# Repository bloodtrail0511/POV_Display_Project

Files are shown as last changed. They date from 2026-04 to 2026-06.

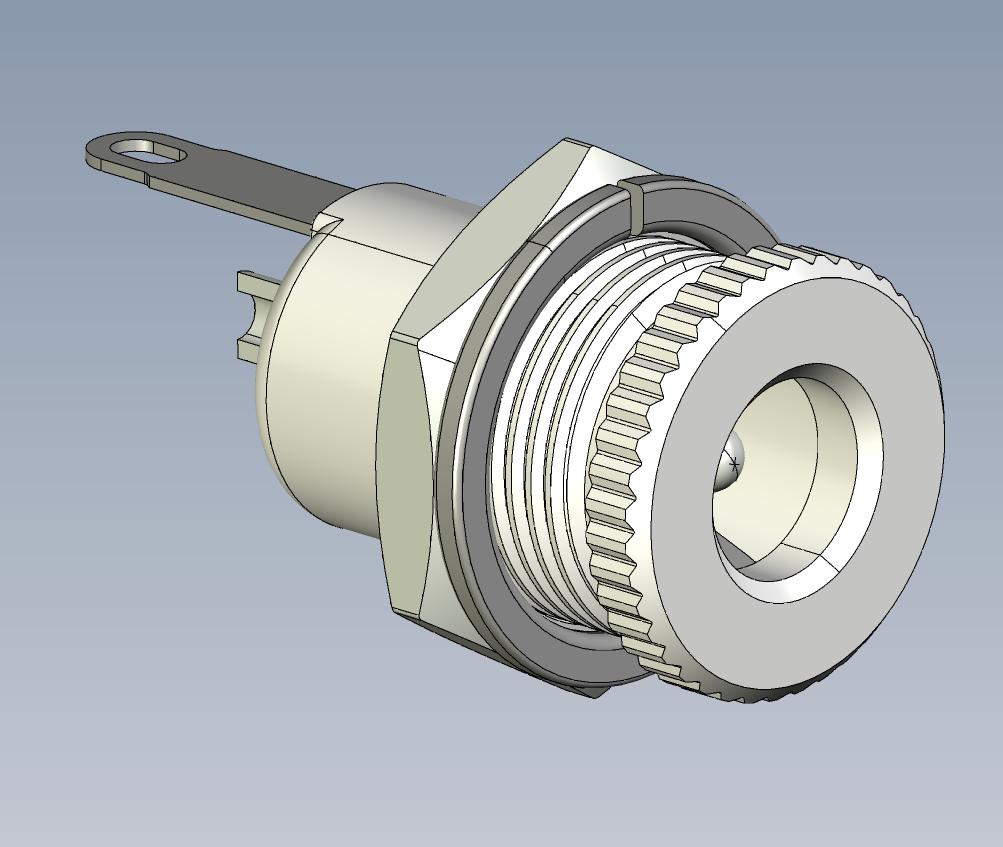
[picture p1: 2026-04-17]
src_by_members/314511041/solidworks_model/connector-5-5x2-1-dc00990-b-1.snapshot.1/Connector_5,5-2,1_DC00990-B_01.png

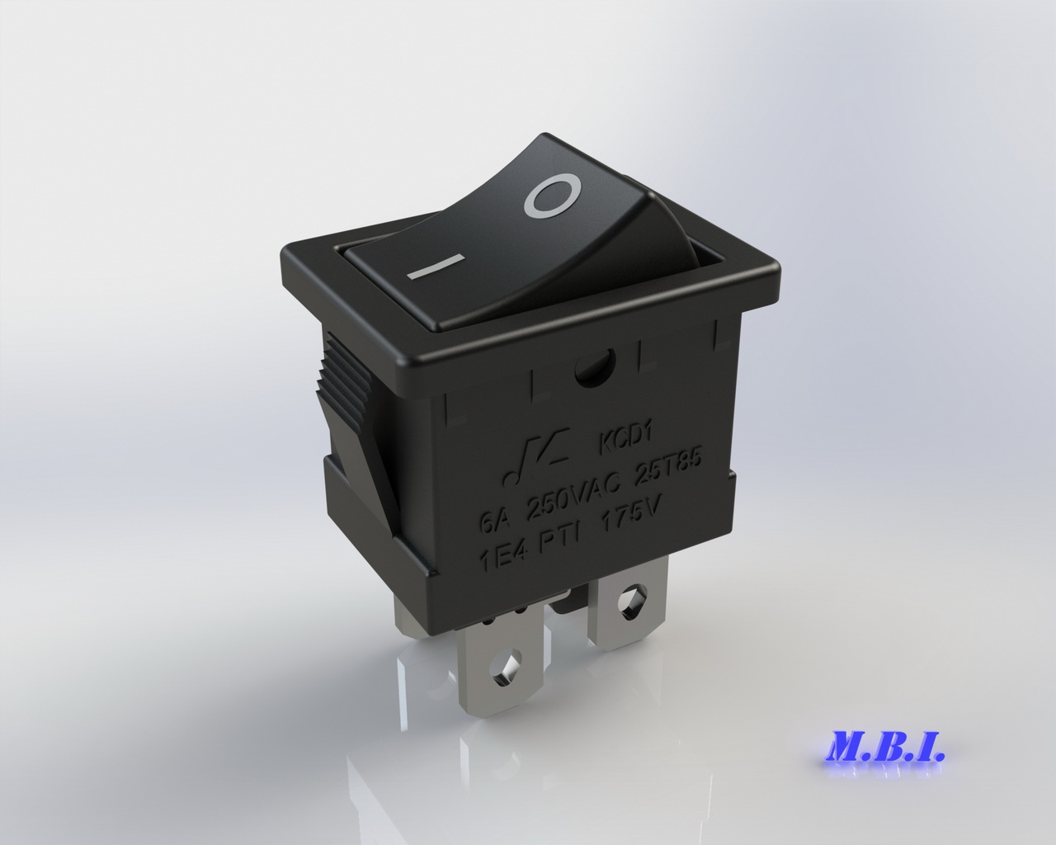
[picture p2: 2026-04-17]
src_by_members/314511041/solidworks_model/rocker-switch-kcd1-104-1.snapshot.1/Renderings/Rocker Switch KCD1-104 IMG_02.JPG

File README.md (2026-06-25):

# 視覺暫留 (POV) 互動遊戲顯示器

本專案是一個基於 Raspberry Pi 與 Linux 作業系統開發的 360 度環狀立體顯示螢幕。利用視覺暫留 (Persistence of Vision, POV) 原理結合高速旋轉的 APA102 LED 燈條，並透過自定義的 Linux Character Device Driver 達到極低延遲的硬體中斷與畫面同步，實現高流暢度的互動遊戲與多媒體展示。

## ✨ 核心技術與系統特色

* **Device Tree Overlay (DTS) 硬體綁定**：撰寫 `.dts` 檔案關閉預設的 `spidev`，將 SPI0 硬體節點直接交由自訂的驅動程式接管，突破 User Space Scheduler 的時間延遲限制。
* **即時硬體同步 (Real-time Synchronization)**：實作 Hall Sensor 核心驅動，精準記錄觸發時間 (`ktime`)，並透過低通濾波演算法計算轉速，解決高速旋轉時的畫面抖動問題。
* **核心級雙重緩衝 (Double Buffering)**：在 Kernel Space 實作 Double Buffer，利用 `Spinlock` 保護共享資源。唯有在 Hall Sensor 觸發 0 度回呼 (Callback) 時才進行畫面交換，完美解決畫面撕裂 (Tearing) 現象。
* **非同步 SPI 傳輸 (Async SPI)**：使用 `hrtimer` 以極高頻率觸發 SPI 傳輸，並利用 `atomic_t` 實作 Busy Flag，防止傳輸重疊。
* **TCP Client-Server 架構**：分離主機端 (Server) 與手把端 (Client)。使用 `SIGIO` 非同步訊號讀取硬體按鍵，透過 Socket 實現多玩家即時連線。
* **虛擬模擬器 (Virtual Device)**：內建基於 OpenCV 開發的虛擬模擬器，可在無實體硬體的情況下，直接於 PC 端進行 UI 渲染、狀態機 (FSM) 轉換與遊戲邏輯的開發。

## 📂 專案目錄結構
```
POV-Display-Project/
├── README.md               # 專案介紹與使用說明
├── Makefile                # 專案頂層控制 Makefile (統籌整體自動化編譯)
├── docs/                   # 存放專題說明文件與簡報
│   └── EOS-Final.pdf
├── dts/                    # 裝置樹重疊設定檔 (Device Tree Overlay)
│   └── pov_apa102.dts
├── drivers/                # Linux 核心驅動程式 (Kernel Space)
│   ├── Makefile            # 核心模組專用 Kbuild Makefile
│   ├── magnet_driver.c     # 霍爾感測器驅動
│   ├── my_btn_driver_v2.c  # 手把按鍵驅動 (Debounce 機制)
│   └── pov_display_driver_v3.c # APA102 SPI 顯示驅動
├── server/                 # 顯示器主機端主程式 (User Space)
│   ├── main_test.cpp
│   ├── main_test_sim.cpp   # PC 端虛擬模擬器
│   ├── pov_display.cpp
│   └── pov_display.hpp
├── client/                 # 遙控器手把端程式 (User Space)
│   └── controller_client.cpp
├── scripts/                # 開機自動化與網路連線腳本
│   ├── pov_auto.service
│   ├── start_client.sh
│   └── start_server.sh
└── assets/                 # 執行時期需要的圖片與影片資源
    ├── icon/
    └── video/
```
* `Makefile` : 編譯所需檔案
* `dts/`：包含 `pov_apa102.dts`，用於重新定義 Raspberry Pi 的 SPI 腳位對應。
* `drivers/`：包含三個 Linux Kernel Modules (`.ko`)。
  * `magnet_driver.c`：霍爾感測器 ISR 與轉速濾波。
  * `my_btn_driver_v2.c`：包含 `delayed_work` 軟體防彈跳 (Debounce) 的按鍵驅動。
  * `pov_display_driver_v3.c`：APA102 LED 燈條 SPI 渲染與時序控制驅動。
* `server/`：主機端應用程式 (C++)，負責 OpenCV 影像處理、狀態機邏輯與 Socket 監聽。
* `client/`：手把端應用程式 (C++)，負責讀取本機驅動訊號並透過 TCP 傳送。
* `scripts/`：NetworkManager 自動連線腳本與 systemd service 設定，實現設備開機自動連線與執行。

## 🚀 編編譯與執行方式

### 1. 修改目錄
將 Makefile 裡面的 `KDIR` 修改為實際用於樹莓派或交叉編譯的 Linux 核心原始碼樹（Kernel Source Tree）目錄。例如：
```makefile
KDIR = /home/ouo/master_degree/class/eos/linux-origin
```

### 2. 編編譯檔案
在開發主機的專案根目錄下執行以下指令，編譯驅動程式、手把端程式與裝置樹重疊檔：
```bash
make all
```

### 3. 檔案上傳
分別將編譯完成的驅動、執行檔與相關腳本透過 `scp` 上傳至對應的 Server、Client 樹莓派（例如工作目錄 `/home/rtes/`）：

**Server (主機端樹莓派) 需上傳：**
* 核心驅動模組：`magnet_driver.ko`、`pov_display_driver_v3.ko`、`my_btn_driver_v2.ko`
* 裝置樹重疊檔：`pov_apa102.dtbo`
* 主程式原始碼：`main_test_serverjoin.cpp`、`pov_display.cpp`、`pov_display.hpp`
* 自動化腳本與服務：`start_server.sh`、`pov_auto.service`
* 多媒體資源資料夾：`assets/`（包含 `icon/` 與 `video/`，務必與主程式放在同一層目錄）

**Client (手把端樹莓派)：**
* 核心驅動模組：`my_btn_driver_v2.ko`
* 交叉編譯執行檔：`controller_client`
* 自動化腳本與服務：`start_client.sh`、`pov_auto.service`

### 4. 在樹莓派(Server)執行main_test.cpp的編譯
登入 Server 樹莓派後，切換至擺放原始碼的目錄，執行以下命令編譯結合 OpenCV 與多執行緒的 POV 主程式：
```bash
g++ -o main_test_serverjoin main_test_serverjoin.cpp pov_display.cpp $(pkg-config --cflags --libs opencv4) -lpthread
```

### 5. 複製DTBO並執行指令
在 **Server 樹莓派** 上，將裝置樹重疊檔複製到系統韌體目錄下：
```bash
sudo cp pov_apa102.dtbo /boot/firmware/overlays/
```
編輯開機組態設定檔以啟用自訂的 overlay：
```bash
sudo nano /boot/firmware/config.txt
```
在檔案的最末端加上以下設定：
```text
dtoverlay=pov_apa102
```
*修改完成後存檔退出，並重啟樹莓派 (`sudo reboot`) 以載入 `/dev/pov_display` 與 `/dev/mag_sensor` 設備節點。*

### 6. 啟用服務設定開機自啟動
請先確認兩台樹莓派上的 `pov_auto.service` 服務檔內，其 `WorkingDirectory` 與 `ExecStart` 腳本（`start_server.sh` / `start_client.sh`）的**絕對路徑**皆正確無誤。接著在兩台樹莓派上分別執行：
```bash
sudo cp pov_auto.service /etc/systemd/system/pov_auto.service
sudo systemctl daemon-reload
sudo systemctl enable pov_auto.service
sudo systemctl start pov_auto.service
```
若需要查看自動啟動與雙機 Wi-Fi 通訊的即時 Debug 日誌，可執行：
```bash
sudo journalctl -u pov_auto.service -f
```

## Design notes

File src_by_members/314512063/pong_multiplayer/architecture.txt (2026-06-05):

Pong Game
|
|-- app_pong_multi.cpp
|   |
|   |-- main game loop
|   |-- OpenCV 畫面
|   |-- Pong 物理
|   |-- P1 / P2 本機擋板
|   |-- P3 / P4 網路擋板
|   |-- POV simulator
|   |-- include "net_server.hpp"
|
|-- net_server.hpp
|   |
|   |-- NetPlayerInput 結構宣告
|   |-- net_players[] 宣告
|   |-- 最多 2 位外部玩家
|   |-- start_network_server()
|   |-- stop_network_server()
|
|-- net_server.cpp
|   |
|   |-- TCP socket server
|   |-- bind() / listen()
|   |-- accept thread
|   |-- client thread
|   |-- P3 / P4 玩家分配
|   |-- atomic input state
|   |-- mutex player allocation
|
|-- pong_client.cpp
|   |
|   |-- 玩家端程式
|   |-- 連線到 server IP
|   |-- 上下鍵控制
|   |-- 傳送 UP / DOWN / QUIT

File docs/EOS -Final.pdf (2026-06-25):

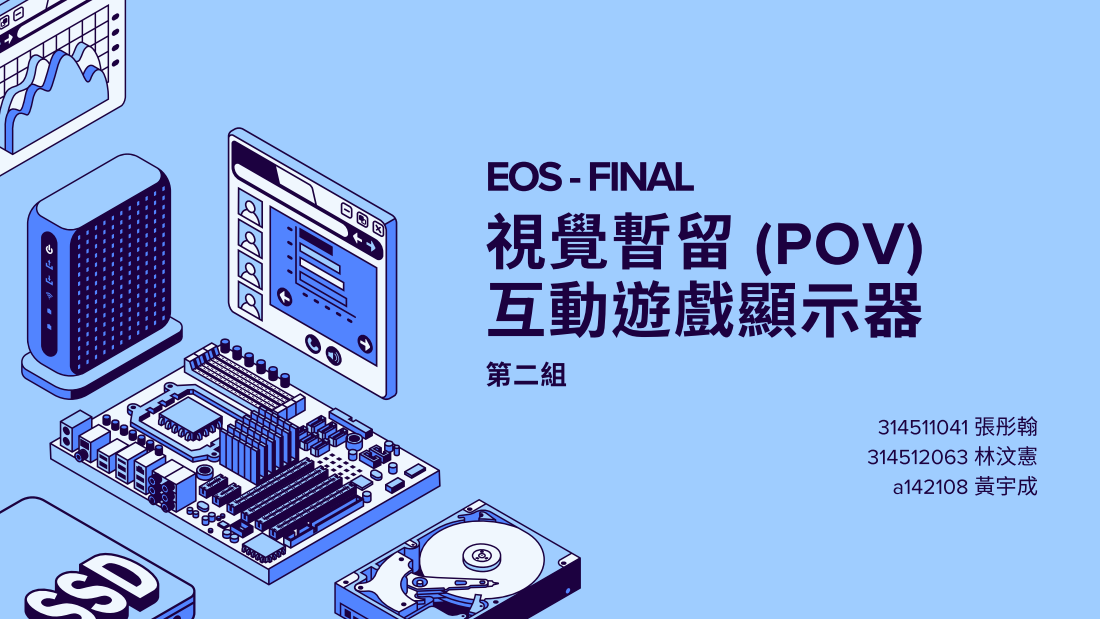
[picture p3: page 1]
EOS-FINAL 視覺暫留 (POV) 互動遊戲顯示器; 第二組; 314511041 張彤翰; 314512063 林汶憲; a142108 黃宇成

# 專題說明-視覺暫留(POV)互動遊戲顯示器

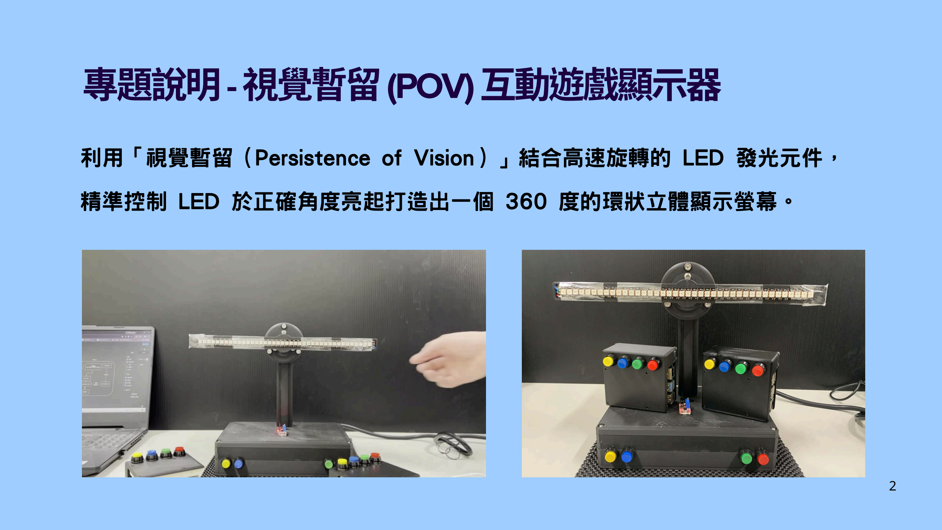
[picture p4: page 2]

利用「視覺暫留（Persistence of Vision）」結合高速旋轉的 LED 發光元件，

精準控制 LED 於正確角度亮起打造出一個 360 度的環狀立體顯示螢幕。

2

## 系統連線架構(TCPclient-server)

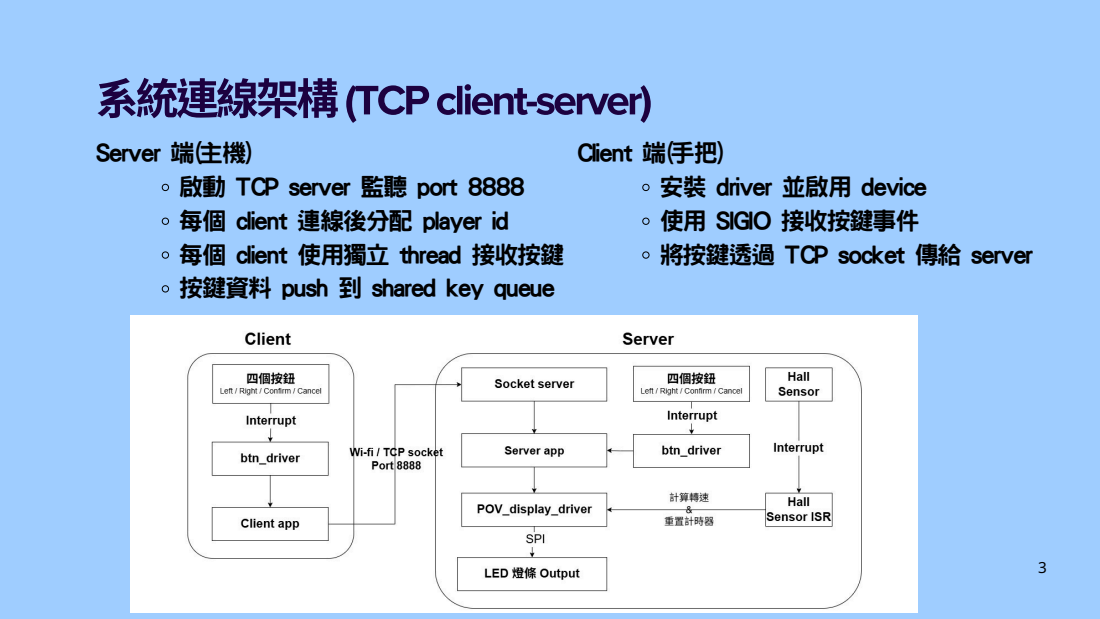
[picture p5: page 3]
Server 端(主機); Client 端(手把)

啟動 TCP server 監聽 port 8888
每個 client 連線後分配 player id
每個 client 使用獨立 thread 接收按鍵
按鍵資料 push 到 shared key queue

安裝 driver 並啟用 device
使用 SIGIO 接收按鍵事件
將按鍵透過 TCP socket 傳給 server

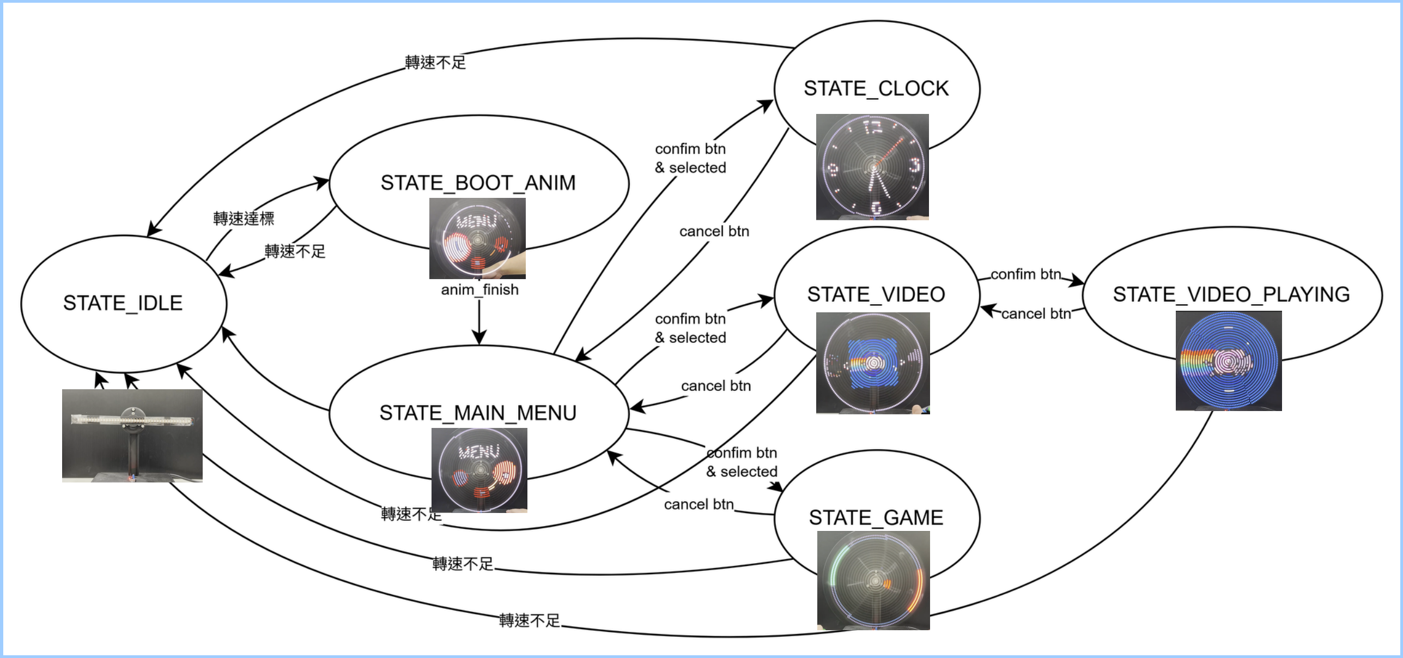
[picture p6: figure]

4

## ServerFSM 架構

主程式使用狀態機 FSM，管理整個系統流程

5

# KernelSpace

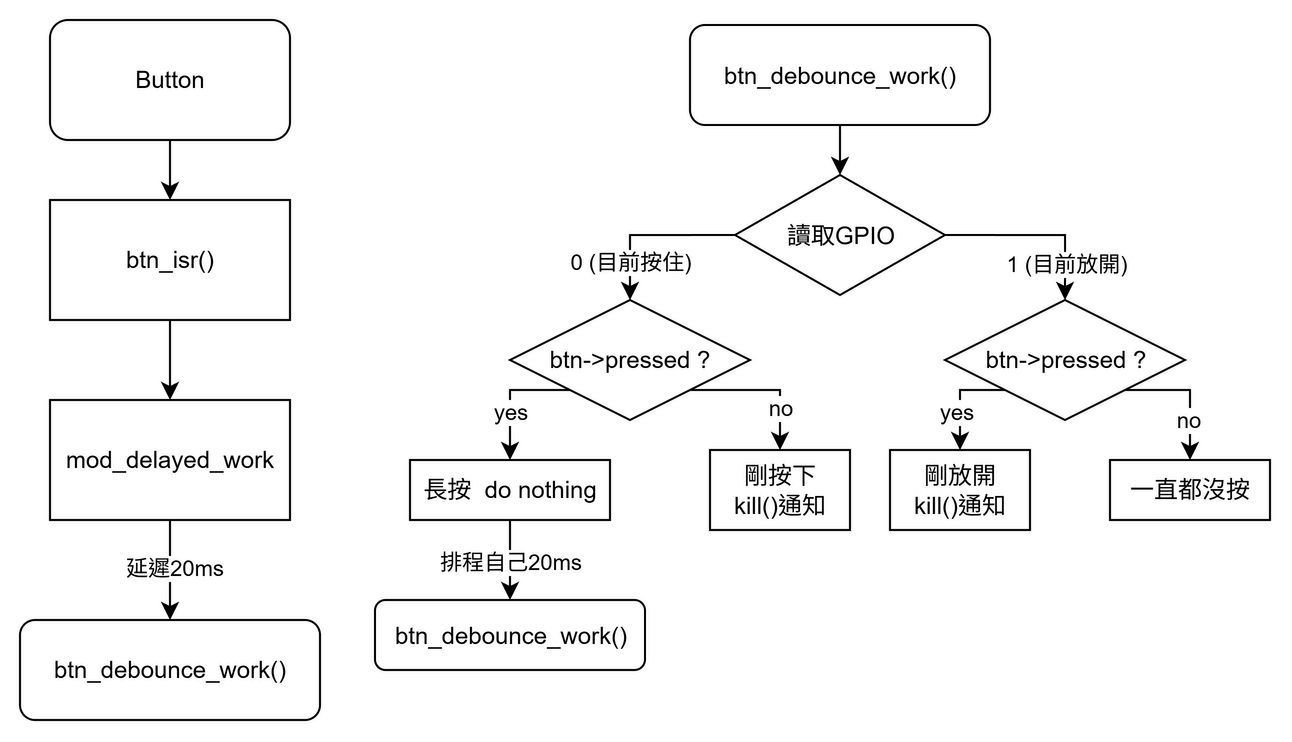
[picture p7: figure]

6

四顆按鍵：left、right、confirm、cancel

ISR 偵測按下與放開，signal通知userspace讀

取狀態

Worker task 實作 debounce 與與狀態判斷

即使放開時 rising interrupt 沒有觸發，

delayed work 也會在下一次檢查時發現已經

release。

## ButtonDriver :遙控器按鈕

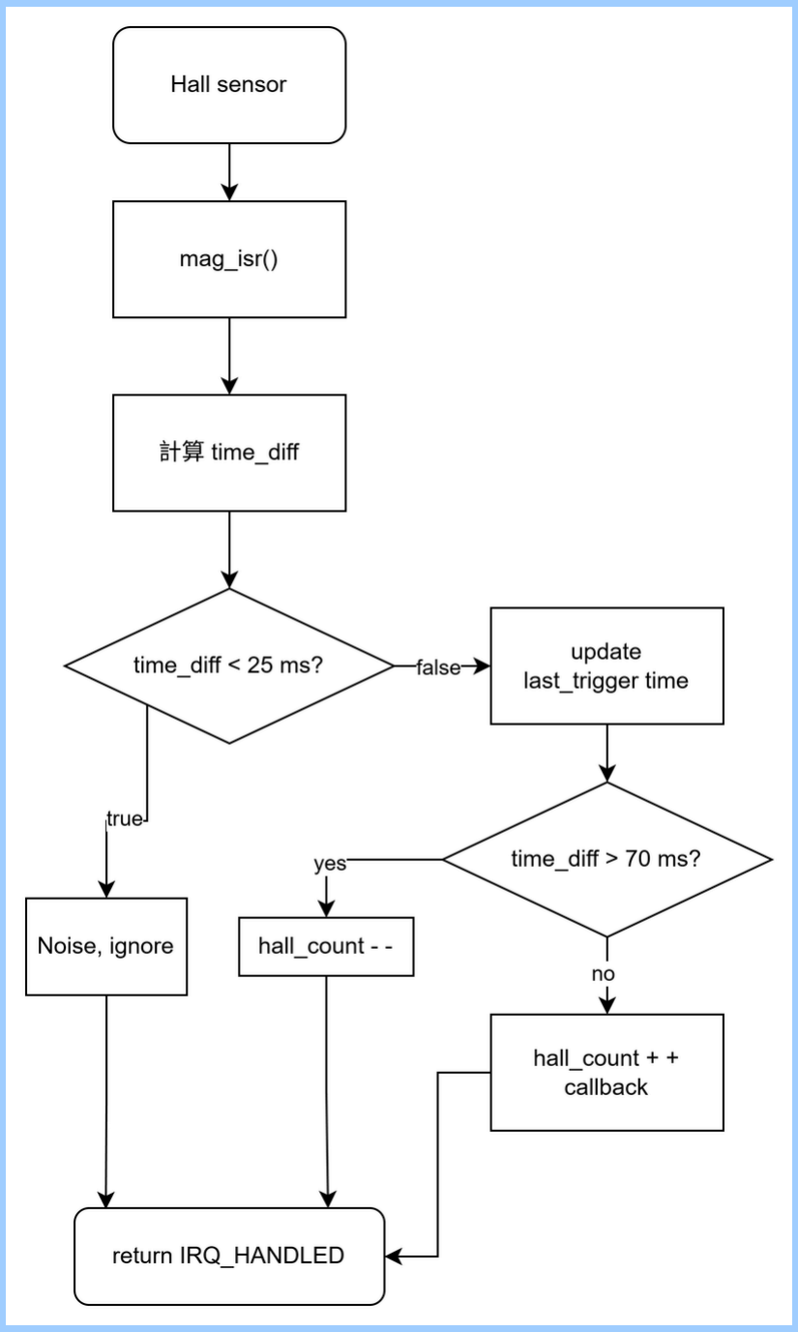
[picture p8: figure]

7

## MagnetDriver : POV系統的角度同步來源

接收 Hall Sensor 的 interrupt 與轉速判斷

記錄每次 Hall 觸發時間，計算並過濾不合理週期，保留穩定轉速

給 userspace 判斷是否正在旋轉，避免誤判

將觸發時間 callback 給 POV driver 進行同步

## POVDisplayDriver : POV顯示

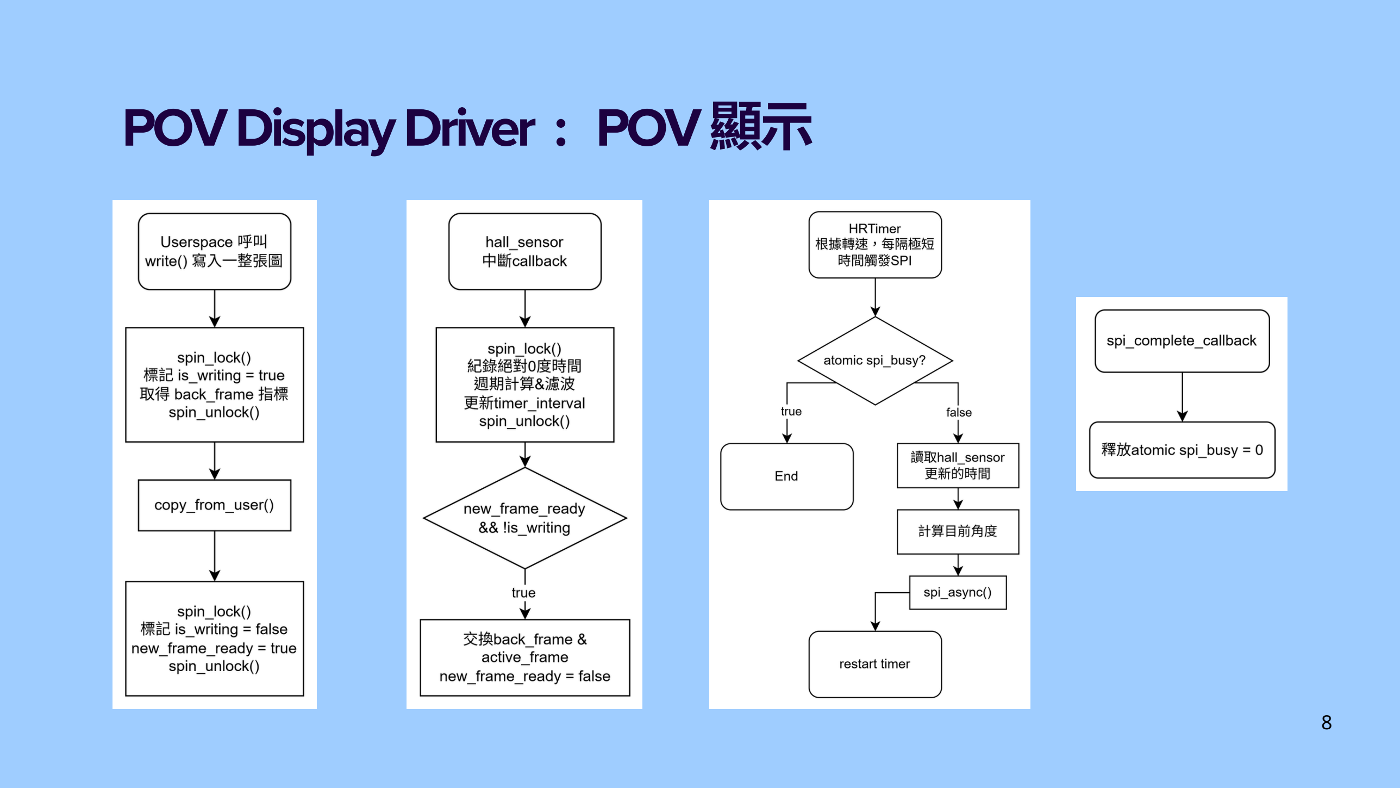
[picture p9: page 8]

8

## POVDisplayDriver-Synchronization

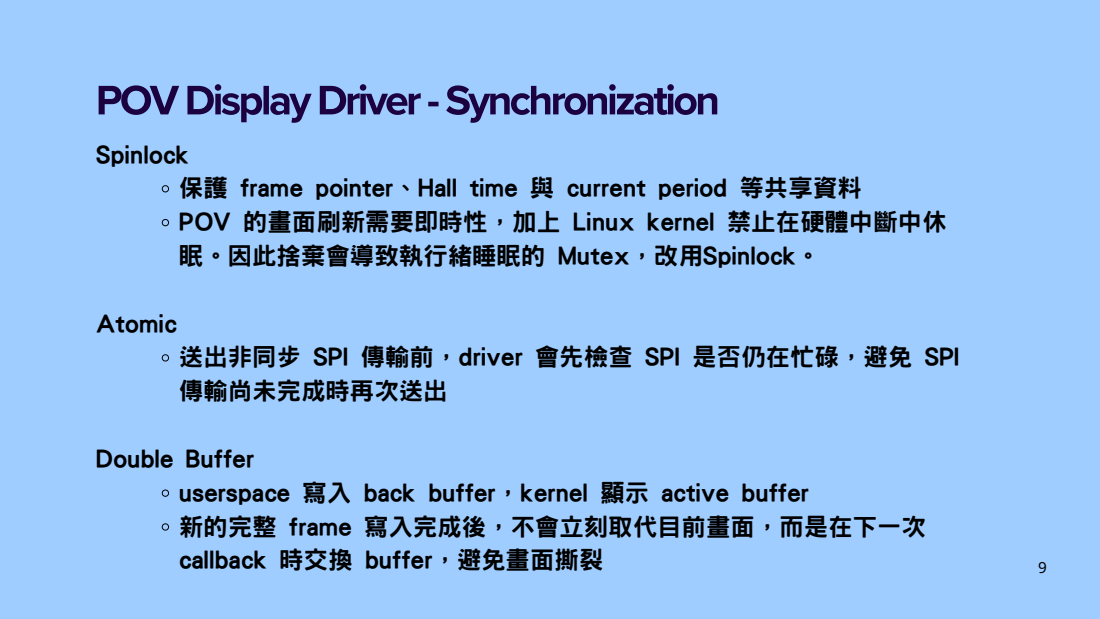
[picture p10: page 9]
Spinlock; Atomic; Double Buffer

保護 frame pointer、Hall time 與 current period 等共享資料
POV 的畫面刷新需要即時性，加上 Linux kernel 禁止在硬體中斷中休
眠。因此捨棄會導致執行緒睡眠的 Mutex，改用Spinlock。

送出非同步 SPI 傳輸前，driver 會先檢查 SPI 是否仍在忙碌，避免 SPI
傳輸尚未完成時再次送出

userspace 寫入 back buffer，kernel 顯示 active buffer
新的完整 frame 寫入完成後，不會立刻取代目前畫面，而是在下一次
callback 時交換 buffer，避免畫面撕裂

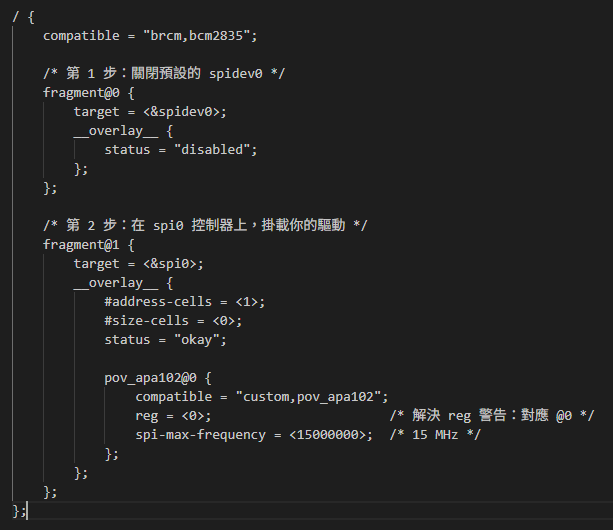
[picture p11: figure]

10

## POVDisplayDriver-DeviceTreeOverlay

為何不直接用 spidev？
RPi 提供的 spidev 只能於 Userspace 使用， 容易受Scheduler影響導致時間延遲
解法：
撰寫自訂的 SPI Client Driver 與 .dts（編譯 成 .dtbo）。讓 Linux 啟動並掃描 Device Tree 時，直接將SPI硬體節點綁定到 POV
driver 中並與其他功能整合，建立完整的即時
顯示流程

11

# UserspaceSpace

# 使用的OS機制

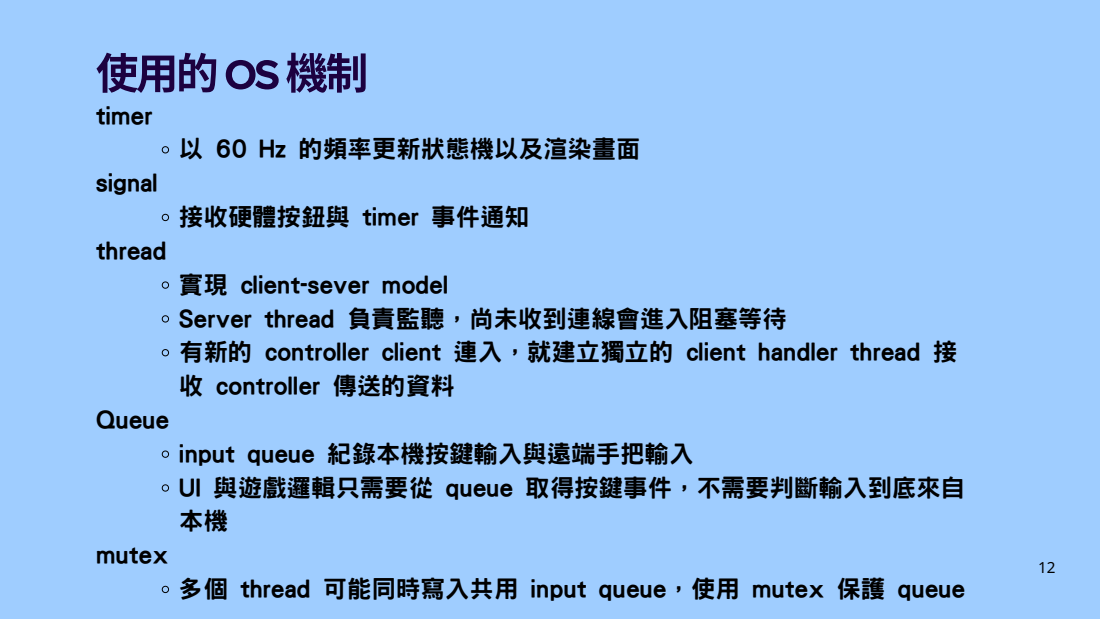
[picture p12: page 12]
timer; 以 60 Hz 的頻率更新狀態機以及渲染畫面; signal; thread; Queue; mutex

接收硬體按鈕與 timer 事件通知

實現 client-sever model
Server thread 負責監聽，尚未收到連線會進入阻塞等待
有新的 controller client 連入，就建立獨立的 client handler thread 接
收 controller 傳送的資料

input queue 紀錄本機按鍵輸入與遠端手把輸入
UI 與遊戲邏輯只需要從 queue 取得按鍵事件，不需要判斷輸入到底來自

多個 thread 可能同時寫入共用 input queue，使用 mutex 保護 queue

## POVDisplayClass

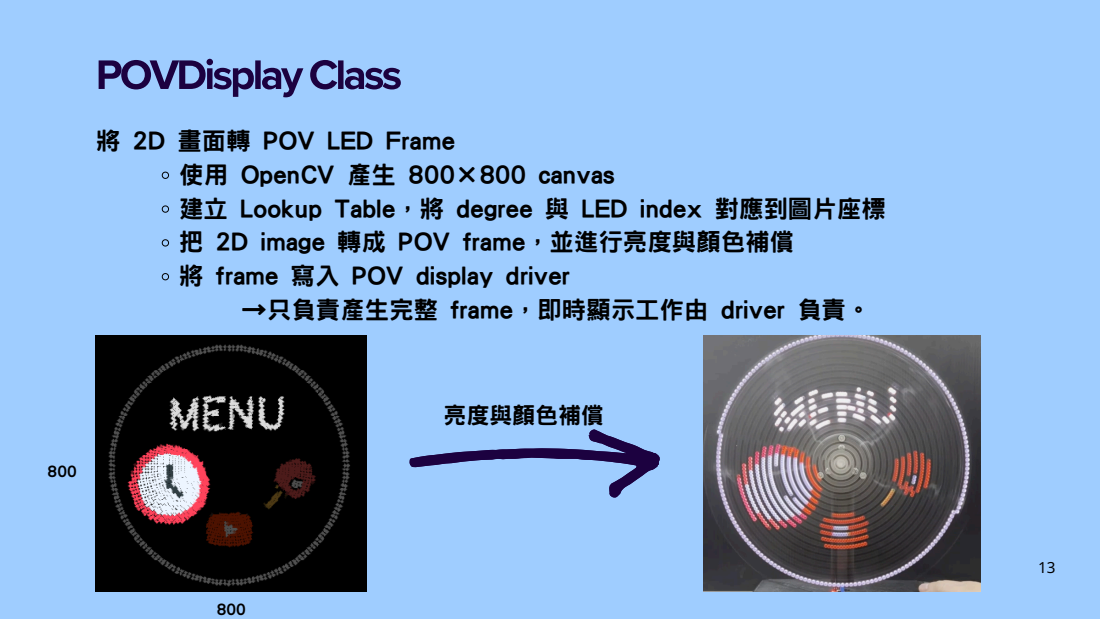
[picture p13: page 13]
亮度與顏色補償

將 2D 畫面轉 POV LED Frame

使用 OpenCV 產生 800×800 canvas
建立 Lookup Table，將 degree 與 LED index 對應到圖片座標
把 2D image 轉成 POV frame，並進行亮度與顏色補償
將 frame 寫入 POV display driver
→只負責產生完整 frame，即時顯示工作由 driver 負責。

## VirtualDevice模擬器

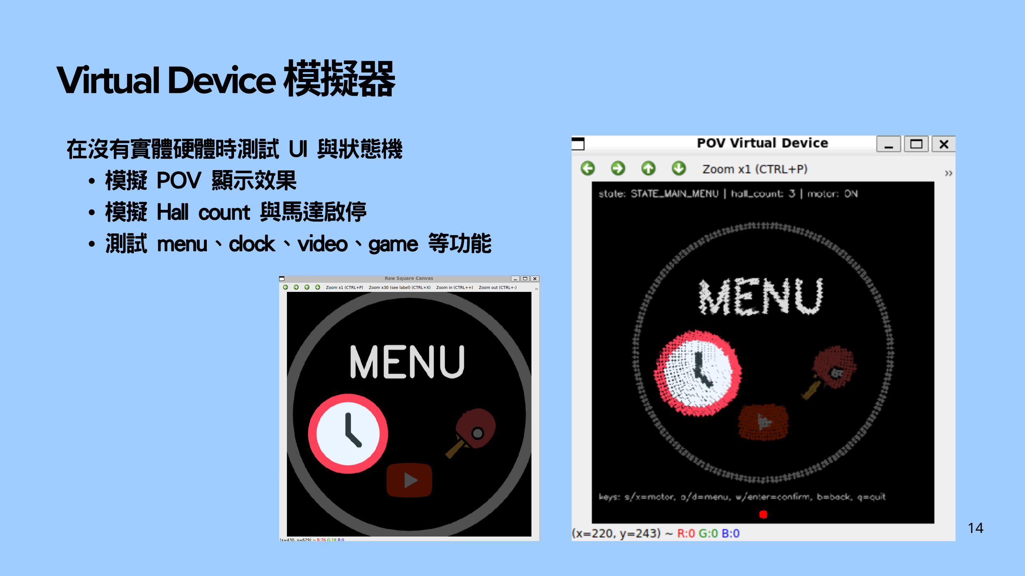
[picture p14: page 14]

14

在沒有實體硬體時測試 UI 與狀態機
模擬 POV 顯示效果
模擬 Hall count 與馬達啟停
測試 menu、clock、video、game 等功能

15

# Demo

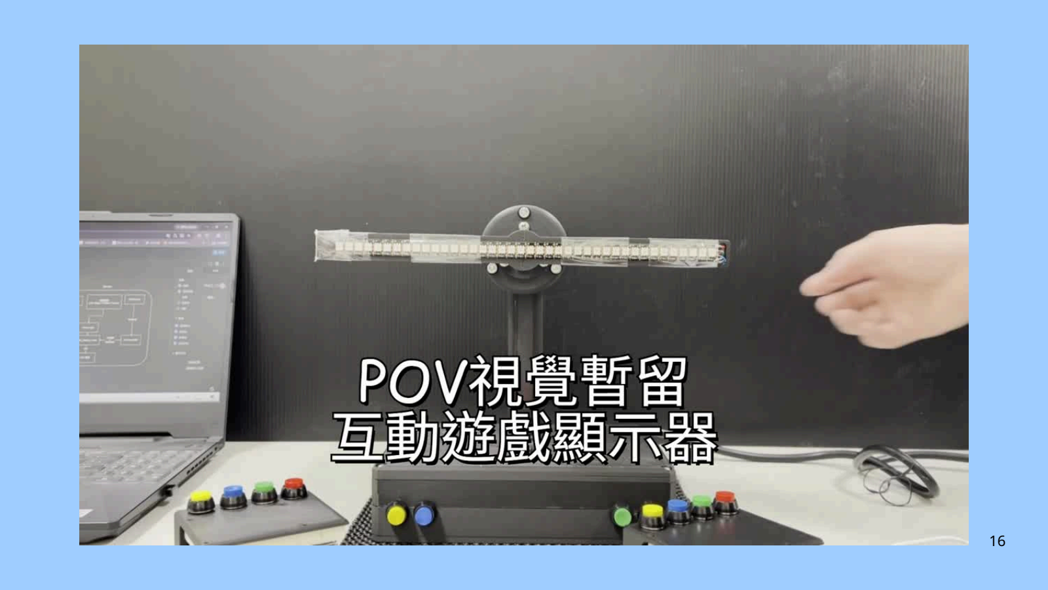
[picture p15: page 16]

16

# 遇到的問題與解決方法

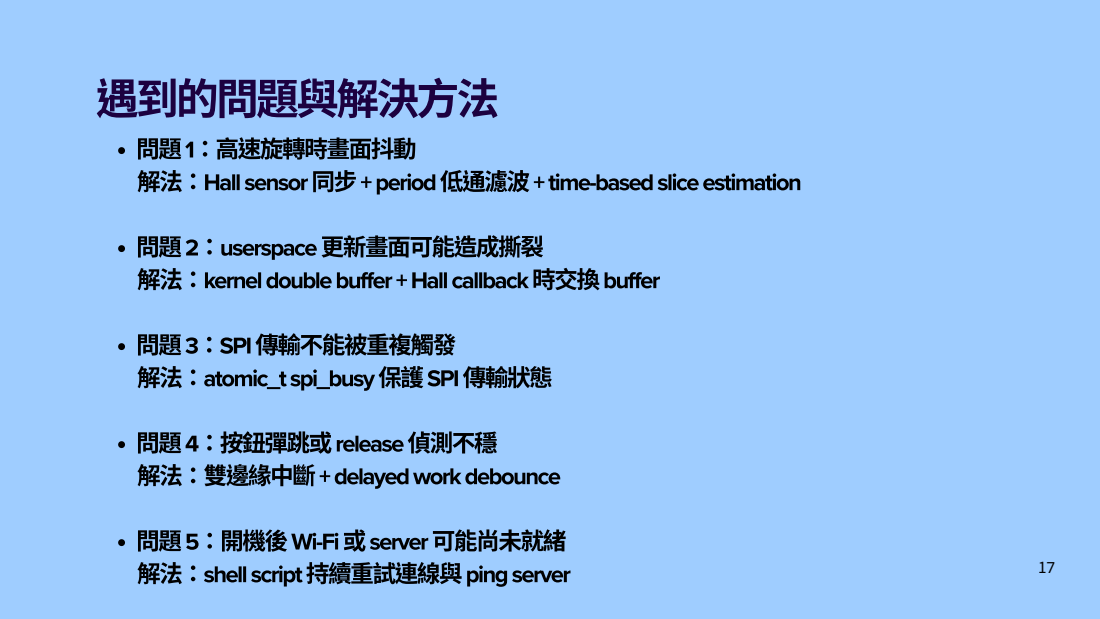
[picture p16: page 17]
問題3：SPI傳輸不能被重複觸發; 解法：atomic_t spi_busy保護SPI傳輸狀態

問題1：高速旋轉時畫面抖動
解法：Hall sensor同步+period低通濾波+ time-basedsliceestimation

問題2：userspace更新畫面可能造成撕裂
解法：kerneldoublebuffer +Hall callback時交換buffer

問題4：按鈕彈跳或release偵測不穩
解法：雙邊緣中斷+delayedworkdebounce

問題5：開機後Wi-Fi或server可能尚未就緒
解法：shell script持續重試連線與pingserver

# 本專題使用到的EOS概念

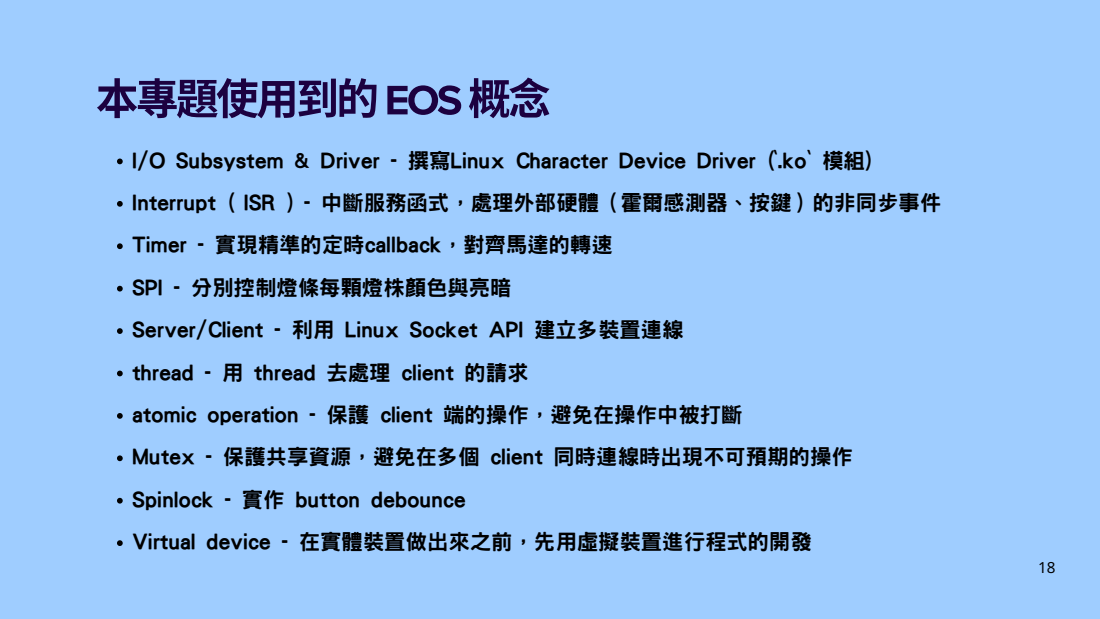
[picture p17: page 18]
SPI - 分別控制燈條每顆燈株顏色與亮暗

I/O Subsystem & Driver - 撰寫Linux Character Device Driver (`.ko

Interrupt ( ISR ) - 中斷服務函式，處理外部硬體（霍爾感測器、按鍵）的非同步事件

Timer - 實現精準的定時callback，對齊馬達的轉速

Server/Client - 利用 Linux Socket API 建立多裝置連線

thread - 用 thread 去處理 client 的請求

atomic operation - 保護 client 端的操作，避免在操作中被打斷

Mutex - 保護共享資源，避免在多個 client 同時連線時出現不可預期的操作

Spinlock - 實作 button debounce

Virtual device - 在實體裝置做出來之前，先用虛擬裝置進行程式的開發

19

Q&A

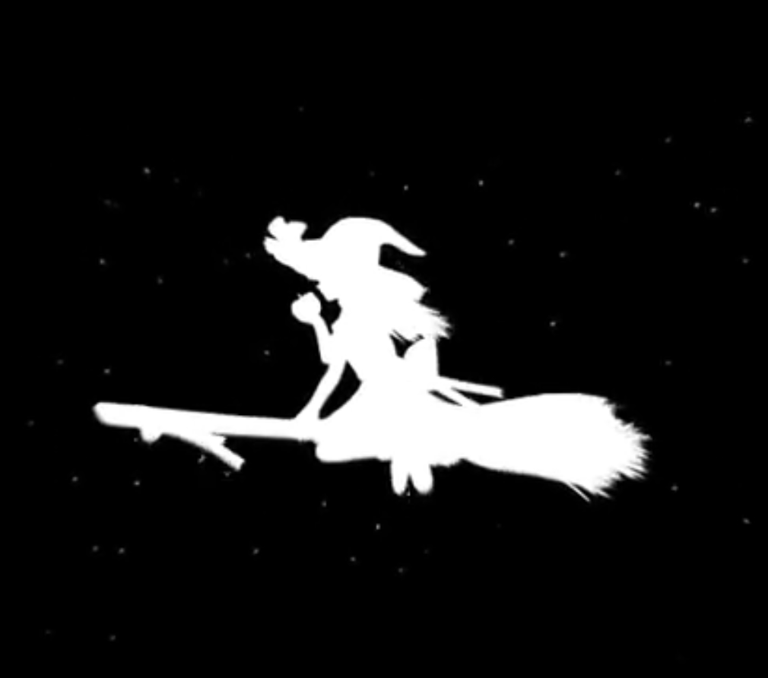
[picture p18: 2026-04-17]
src_by_members/314511041/bad_apple.png

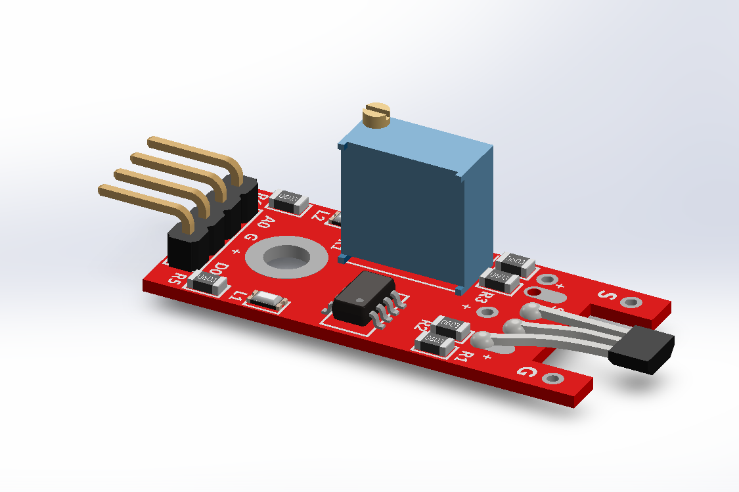
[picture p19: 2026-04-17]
src_by_members/314511041/solidworks_model/hall-effect-sensor-2.snapshot.2/Hall Effect Sensor.png

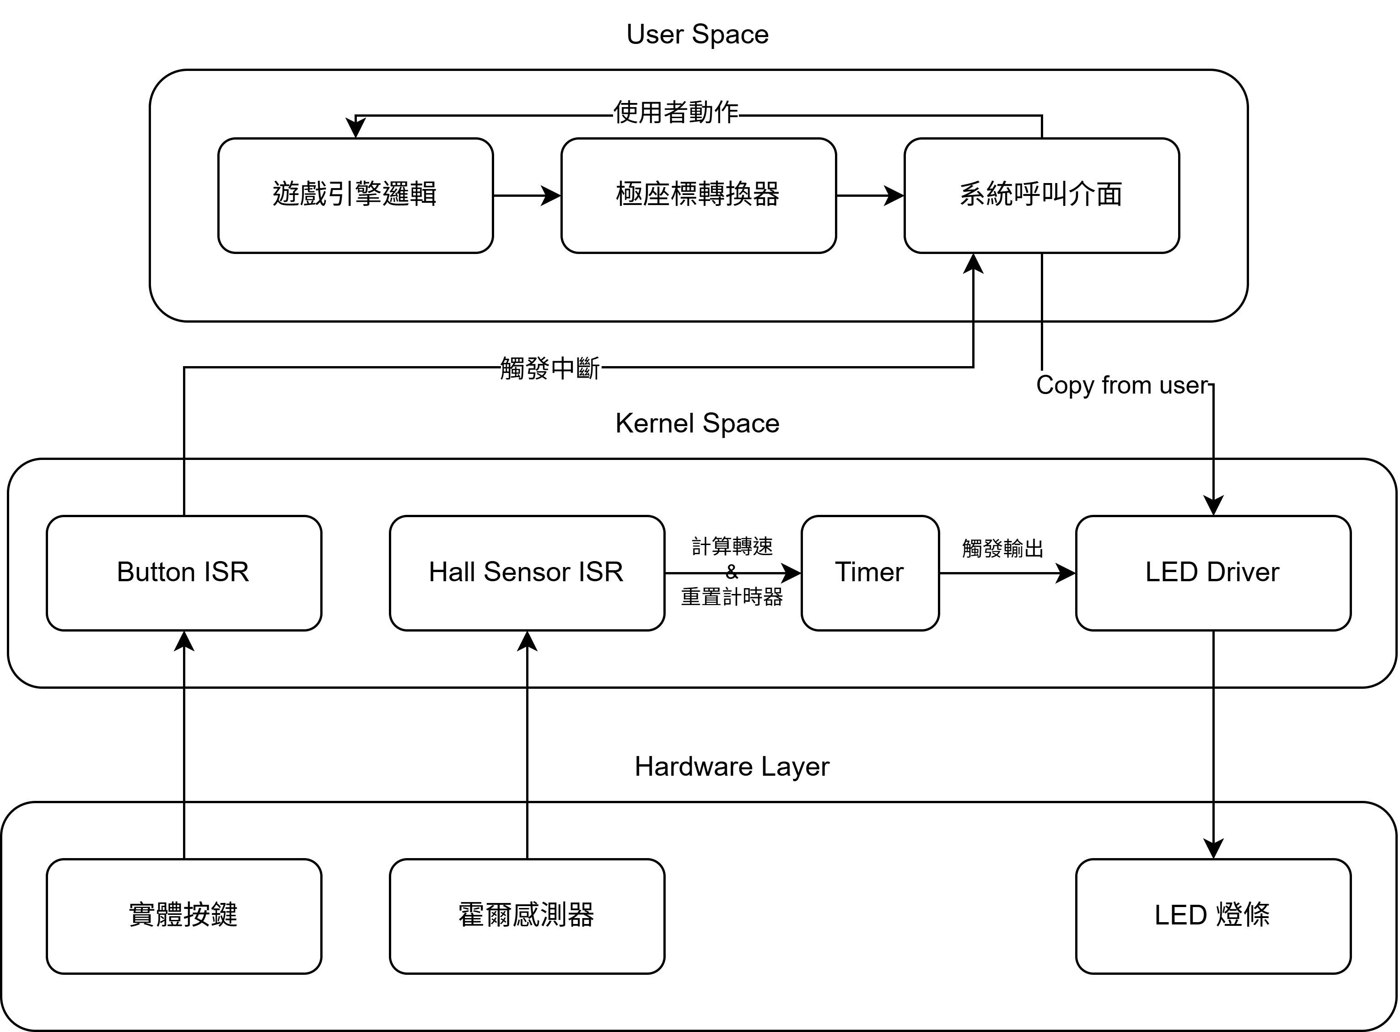
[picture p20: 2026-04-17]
src_by_members/314511041/from_vm/系統架構圖.png

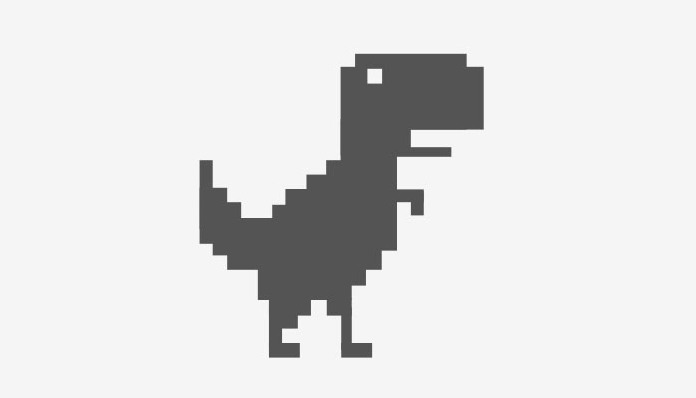
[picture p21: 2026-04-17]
src_by_members/314511041/from_vm/dino.jpg

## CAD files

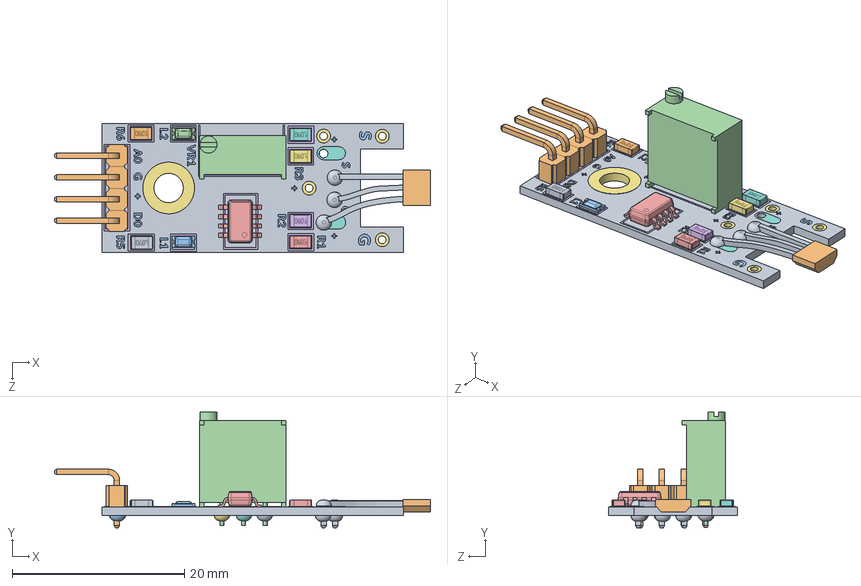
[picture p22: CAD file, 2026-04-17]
src_by_members/314511041/solidworks_model/hall-effect-sensor-2.snapshot.2/Linear Magnetic Hall Effect Switches.SLDASM
43.6 x 13.4 x 15.0 mm
Pins.step
Sensor-0.step
Fusion002.step
Trimpot.step
lm393.step
Pad003.step
Pad001.step
Pad002.step
PCB.step
PIN HEADER, 1X4, 2.54 mm.step
Led.step
Led (1).step
Resistor.step
Resistor (1).step
Resistor (2).step
Resistor (3).step
Resistor (4).step
Resistor (5).step
Pad (2).step
Pad (4).step
Pad (3).step
Pad (5).step
Pad (2) (1).step
Pad (2) (2).step
Pad (2) (3).step x 7
Pad.step
Pad (1).step
Pad (6).step

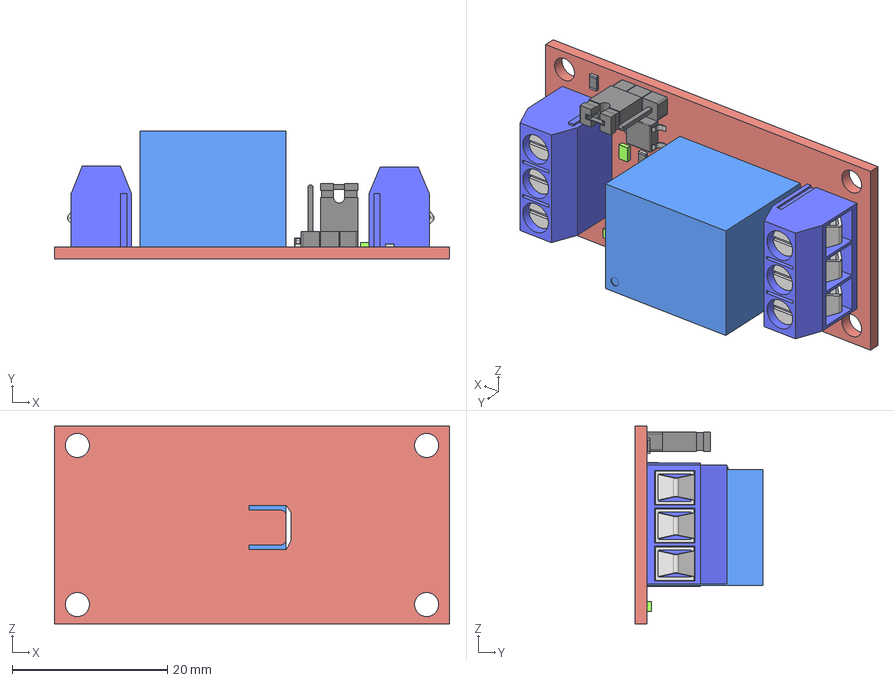
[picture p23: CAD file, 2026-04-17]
src_by_members/314511041/solidworks_model/5v-relay-module-1.snapshot.1/5V_Relay_HW-803.step
50.9 x 16.4 x 25.5 mm

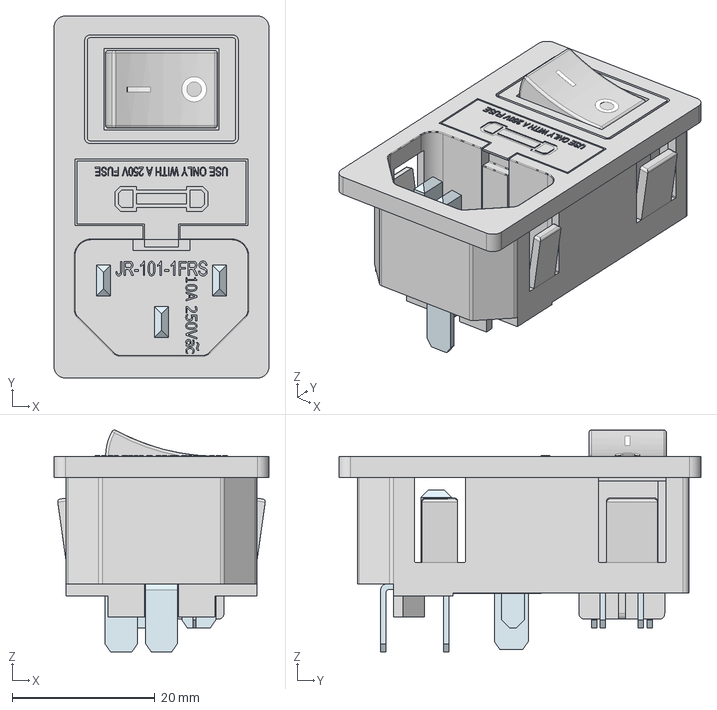
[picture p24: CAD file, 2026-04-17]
src_by_members/314511041/solidworks_model/ael-jr-101-1frs-1.snapshot.1/AEL-JR-101-1FRS.stp
30.2 x 50.8 x 31.1 mm

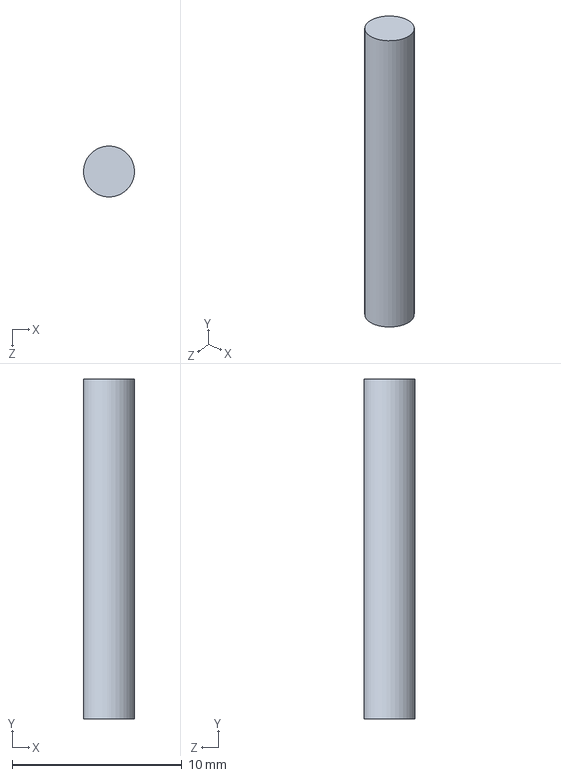
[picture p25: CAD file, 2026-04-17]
src_by_members/314511041/solidworks_model/axle_short.SLDPRT
3.00 x 20.0 x 3.00 mm

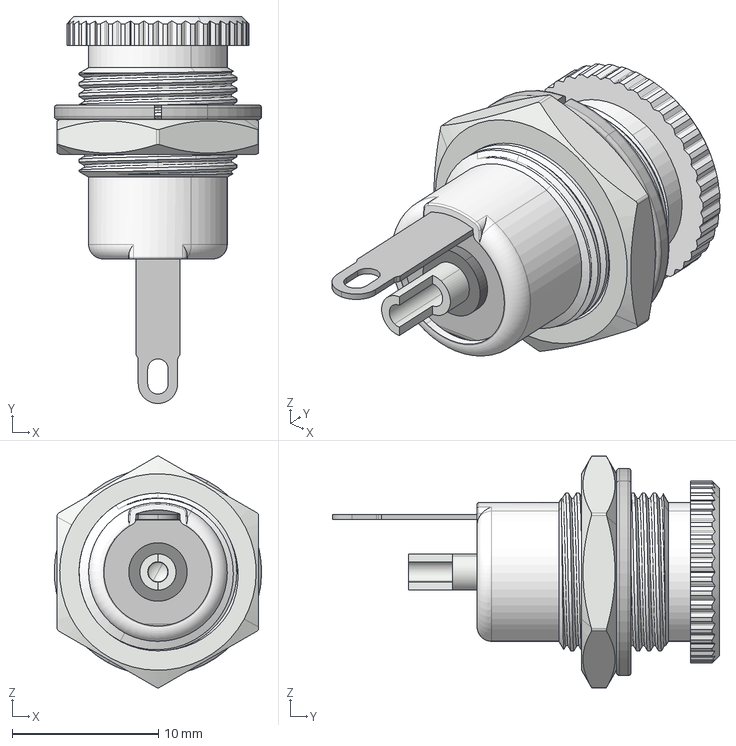
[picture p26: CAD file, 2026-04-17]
src_by_members/314511041/solidworks_model/connector-5-5x2-1-dc00990-b-1.snapshot.1/Connector_5,5-2,1_DC00990-B.stp
14.2 x 26.5 x 15.9 mm

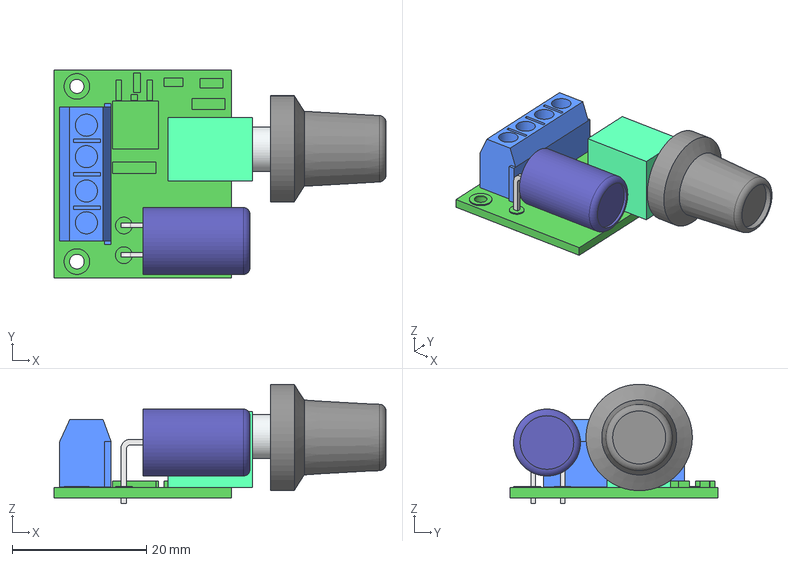
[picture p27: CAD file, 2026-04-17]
src_by_members/314511041/solidworks_model/dc-motor-speed-controller-module-1.snapshot.6/Controlador velocidad Motor PWM-Grupo.step
49.5 x 31.0 x 17.8 mm
POTENCIOMETRO_CAJA
EJE
potenciometro
condensador
PIN
PIN001

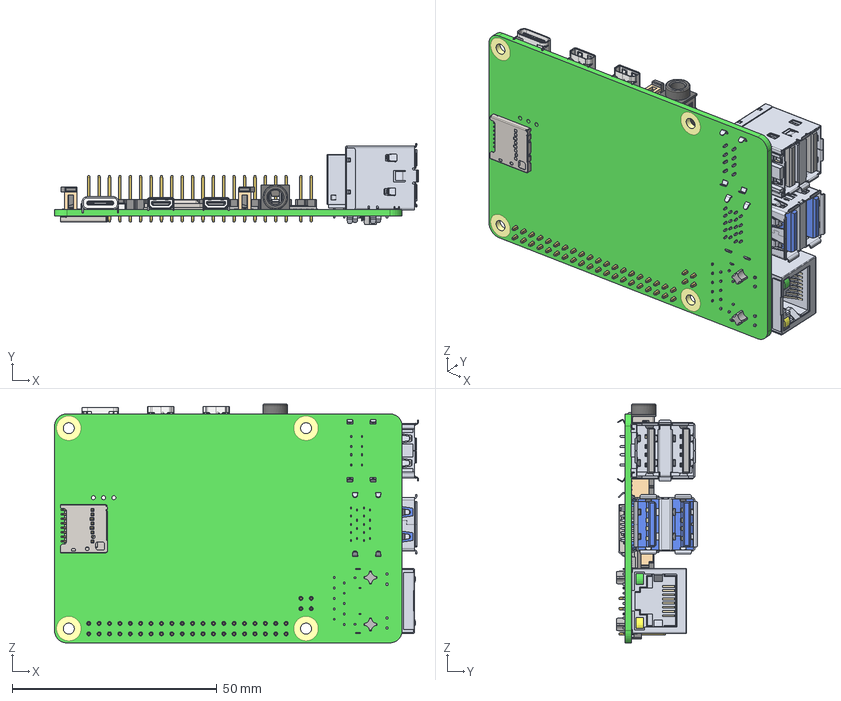
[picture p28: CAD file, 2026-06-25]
src_by_members/314511041/solidworks_model/raspberry-pi-4-model-b-9.snapshot.1/Raspberry Pi 4 Model B.step
89.0 x 19.9 x 58.4 mm
PCB, RPi4ModelB
Broadcom BCM2711B0 CPU, RPi4ModelB
2.54 mm DUPONT MALE PIN HEADER, POE, 2X2, RPi4ModelB
2.54 mm DUPONT MALE PIN HEADER, IO, 2X20, RPi4ModelB
Camera Connector, RPi4ModelB
Microphone Plug, RPi4ModelB
Display Connector, RPi4ModelB
Gigabit Ethernet Port, RPi4ModelB
Female Micro HDMI Connector, RPi4ModelB x 2
Female USB Type C Connector, RPi4ModelB
2X USB3.0 PORTS, RPi4ModelB
91D77 D9WHV 778K, 4 GB LPDDR4 SDRAM, RPi4ModelB
Cypress CYW43455 Wireless Module Cover, RPi4ModelB
SD Card Slot, RPi4ModelB
VIA VL805 PCIe USB 3.0 controller, RPi4ModelB
2X USB2.0 PORTS, RPi4ModelB
Broadcom BCM54213PE Gigabit Ethernet Transceiver, RPi4ModelB
MxL7704 Universal PMIC, RPi4ModelB

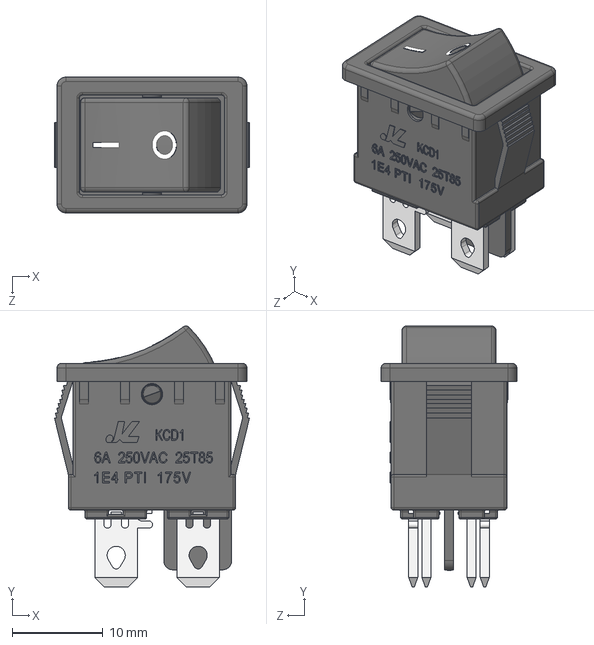
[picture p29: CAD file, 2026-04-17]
src_by_members/314511041/solidworks_model/rocker-switch-kcd1-104-1.snapshot.1/Rocker Switch KCD1-104.STEP
21.5 x 28.8 x 15.0 mm

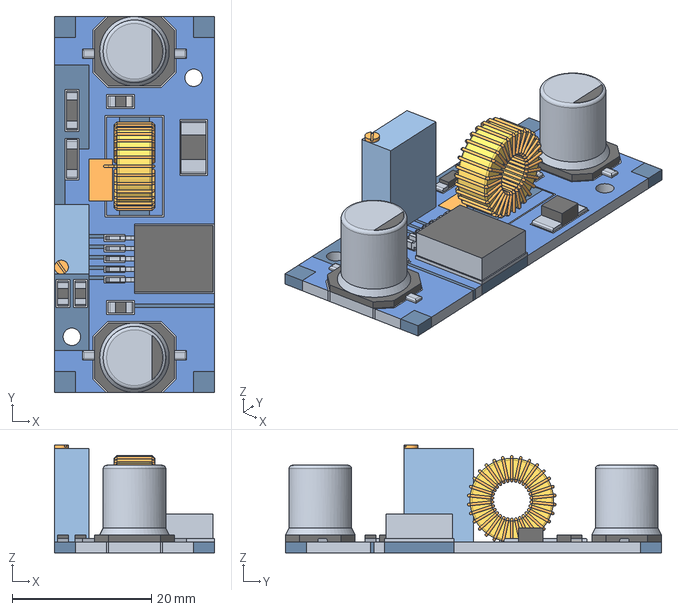
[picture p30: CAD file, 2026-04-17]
src_by_members/314511041/solidworks_model/step-down-xl4015-1.snapshot.2/Step Down XL4015.step
23.0 x 54.0 x 15.5 mm

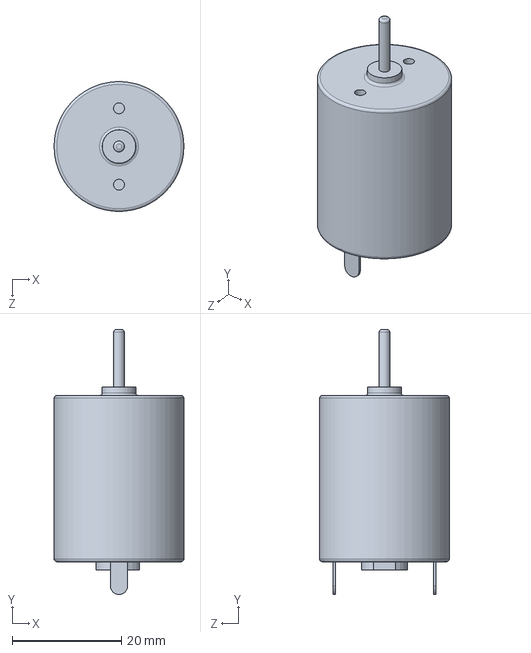
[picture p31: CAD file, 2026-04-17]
src_by_members/314511041/solidworks_model/motor.SLDPRT
23.8 x 48.6 x 23.8 mm

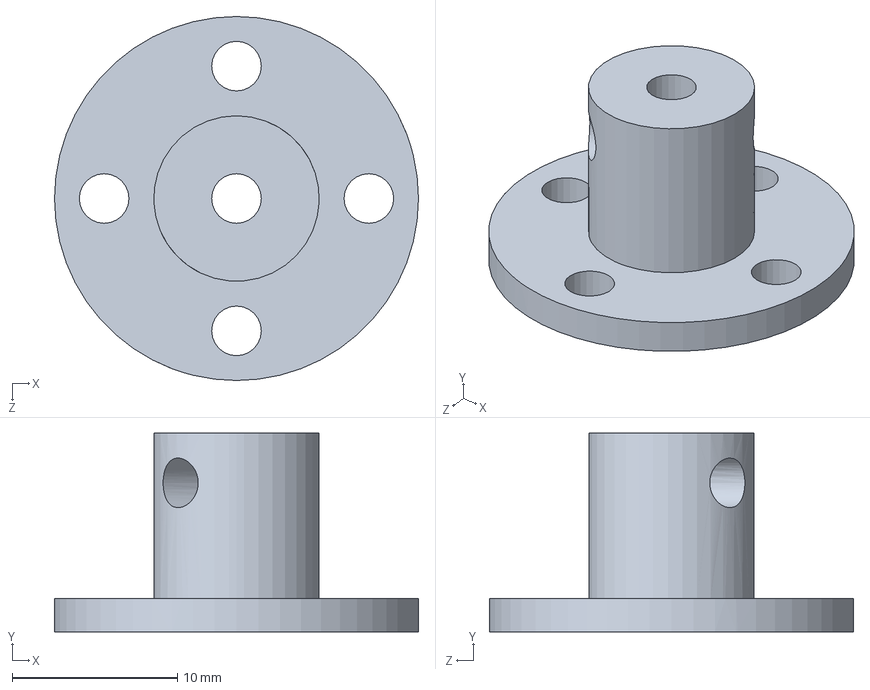
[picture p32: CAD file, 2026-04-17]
src_by_members/314511041/solidworks_model/flange.SLDPRT
22.0 x 12.0 x 22.0 mm

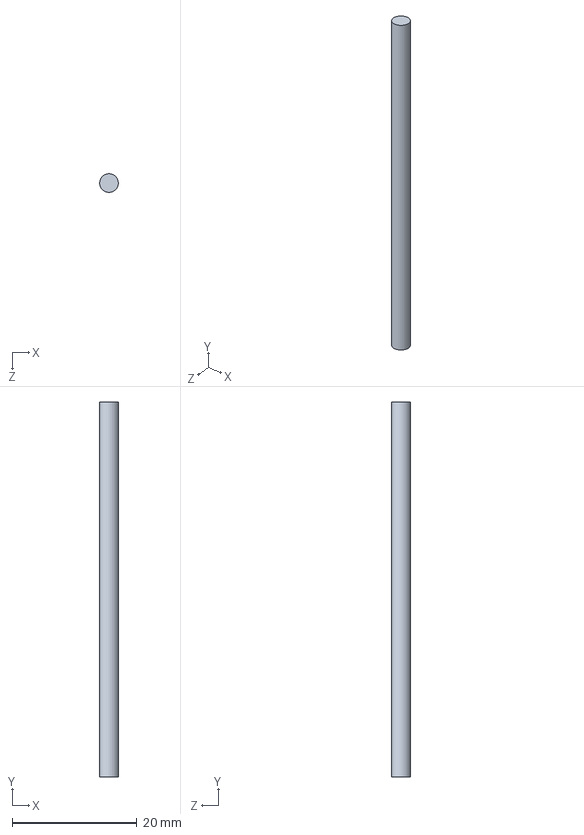
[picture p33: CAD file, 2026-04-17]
src_by_members/314511041/solidworks_model/axle_long.SLDPRT
3.00 x 60.0 x 3.00 mm

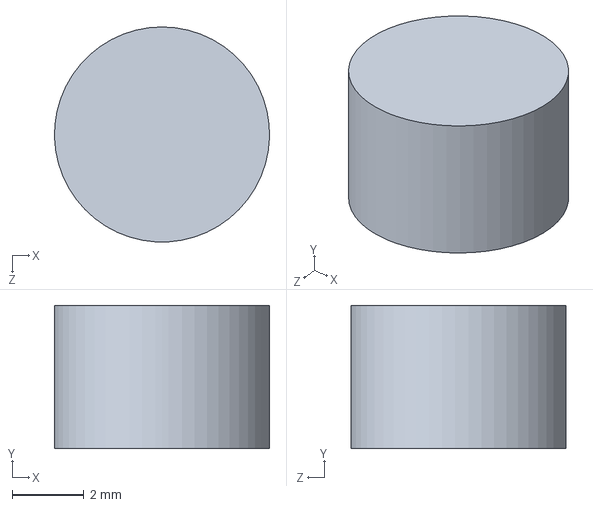
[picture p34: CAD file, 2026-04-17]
src_by_members/314511041/solidworks_model/magnet.SLDPRT
6.00 x 4.00 x 6.00 mm

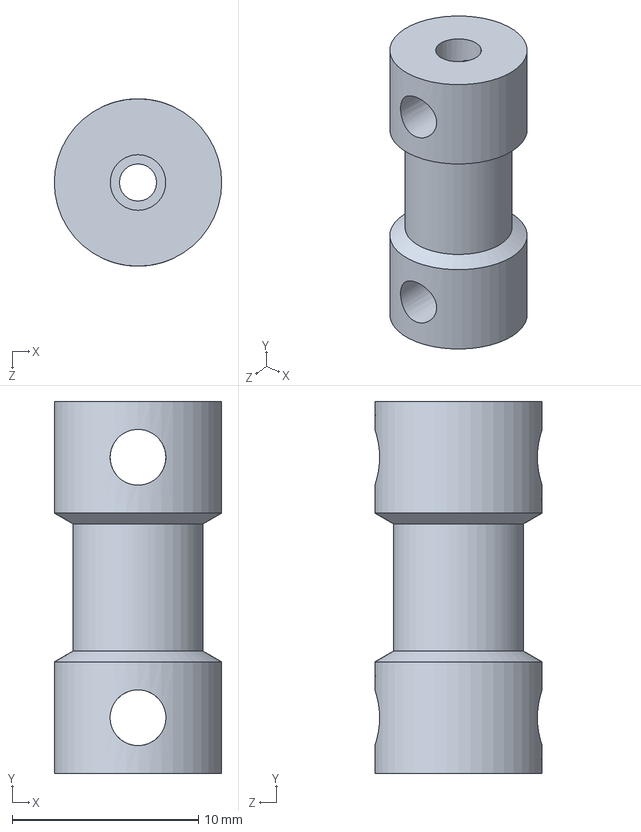
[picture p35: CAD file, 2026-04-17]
src_by_members/314511041/solidworks_model/coupling.SLDPRT
9.00 x 20.0 x 9.00 mm

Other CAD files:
src_by_members/314511041/solidworks_model/led_strip.SLDPRT
src_by_members/314511041/solidworks_model/slip_ring.SLDPRT
src_by_members/314511041/solidworks_model/power_supply_12v.SLDPRT
src_by_members/314511041/solidworks_model/dc-motor-speed-controller-module-1.snapshot.6/Controlador velocidad Motor PWM-Grupo.obj
src_by_members/314511041/solidworks_model/rocker-switch-kcd1-104-1.snapshot.1/Rocker Switch KCD1-104.x_b
src_by_members/314511041/solidworks_model/step-down-xl4015-1.snapshot.2/Step Down XL4015.sldprt
src_by_members/314511041/solidworks_model/step-down-xl4015-1.snapshot.2/Step Down XL4015.x_t

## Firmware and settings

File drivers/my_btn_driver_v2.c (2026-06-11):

#include <linux/kernel.h>
#include <linux/init.h>
#include <linux/module.h>
#include <linux/kdev_t.h>
#include <linux/fs.h>
#include <linux/cdev.h>
#include <linux/device.h>
#include <linux/gpio.h>
#include <linux/interrupt.h>
#include <linux/ktime.h>
#include <linux/uaccess.h>      // for copy_to_user
#include <linux/workqueue.h>    // for delayed_work
#include <linux/spinlock.h>

/*
 * 目前按鈕 GPIO 設定
 * 注意：這裡是 BCM GPIO 編號，不是實體 pin 編號。
 */
// #define GPIO_LEFT    17
// #define GPIO_RIGHT   5
// #define GPIO_CONFIRM 25
// #define GPIO_CANCEL  16
#define GPIO_LEFT 27
#define GPIO_RIGHT 22
#define GPIO_CONFIRM 23
#define GPIO_CANCEL 24

/*
 * delayed work debounce 時間
 * 20ms 通常可以濾掉大部分機械按鈕彈跳。
 * 如果還會彈跳，可以改成 30 或 50。
 */
#define DEBOUNCE_DELAY_MS 20

dev_t dev = 0;
static struct class *dev_class;
static struct cdev my_cdev;

/*
 * FASYNC 結構，用來發送 SIGIO 給 userspace
 */
static struct fasync_struct *async_queue;

/*
 * last_pressed_key 由 delayed work 寫入，由 read() 讀取。
 * 用 spinlock 保護，避免 read 與 work 同時存取。
 */
static uint8_t last_pressed_key = 0;
static DEFINE_SPINLOCK(key_lock);

/*
 * 每顆按鈕各自保存 GPIO、IRQ、按鍵字元、pressed 狀態與 delayed work。
 * pressed:
 *   false = 目前是放開狀態
 *   true  = 目前是按下狀態
 */
struct btn_info {
    int gpio;
    int irq;
    uint8_t key;
    const char *name;
    bool pressed;
    struct delayed_work work;
};

static struct btn_info buttons[] = {
    { .gpio = GPIO_LEFT,    .irq = -1, .key = 'a', .name = "btn_left",    .pressed = false },
    { .gpio = GPIO_RIGHT,   .irq = -1, .key = 'd', .name = "btn_right",   .pressed = false },
    { .gpio = GPIO_CONFIRM, .irq = -1, .key = 'w', .name = "btn_confirm", .pressed = false },
    { .gpio = GPIO_CANCEL,  .irq = -1, .key = 'b', .name = "btn_cancel",  .pressed = false },
};

#define NUM_BUTTONS ARRAY_SIZE(buttons)

static int __init my_btn_driver_init(void);
static void __exit my_btn_driver_exit(void);

/*************** Driver functions **********************/
static int my_btn_open(struct inode *inode, struct file *file);
static int my_btn_release(struct inode *inode, struct file *file);
static ssize_t my_btn_read(struct file *filp, char __user *buf, size_t len, loff_t *off);
static int my_btn_fasync(int fd, struct file *filp, int mode);
/******************************************************/

static struct file_operations fops =
{
    .owner = THIS_MODULE,
    .read = my_btn_read,
    .open = my_btn_open,
    .release = my_btn_release,
    .fasync = my_btn_fasync,
};

static int my_btn_open(struct inode *inode, struct file *file)
{
    pr_info("Device File Opened...!!!\n");
    return 0;
}

static int my_btn_release(struct inode *inode, struct file *file)
{
    /*
     * 當檔案關閉時，把 FASYNC 佇列清空
     */
    fasync_helper(-1, file, 0, &async_queue);
    pr_info("Device File Closed...!!!\n");
    return 0;
}

/*
 * 支援 userspace 設定 FASYNC
 */
static int my_btn_fasync(int fd, struct file *filp, int mode)
{
    return fasync_helper(fd, filp, mode, &async_queue);
}

/*
 * Userspace 收到 SIGIO 後，呼叫 read() 讀取按鍵值。
 */
static ssize_t my_btn_read(struct file *filp, char __user *buf, size_t len, loff_t *off)
{
    uint8_t key;
    unsigned long flags;

    if (len < 1)
        return -EINVAL;

    spin_lock_irqsave(&key_lock, flags);
    key = last_pressed_key;

    /*
     * 讀完之後清空，避免重複讀取。
     */
    last_pressed_key = 0;
    spin_unlock_irqrestore(&key_lock, flags);

    if (copy_to_user(buf, &key, 1))
        return -EFAULT;

    return 1;
}

/*************** Button debounce work **********************/

/*
 * debounce work 會在中斷後延遲 DEBOUNCE_DELAY_MS 執行。
 * 此時再讀 GPIO，判斷按鈕最後穩定狀態。
 *
 * 電路假設：
 *   GPIO 上拉到 3.3V
 *   按下時接 GND
 *
 * 所以：
 *   gpio_get_value() == 0 代表按下
 *   gpio_get_value() == 1 代表放開
 */
static void btn_debounce_work(struct work_struct *work)
{
    struct btn_info *btn;
    int value;
    unsigned long flags;

    btn = container_of(to_delayed_work(work), struct btn_info, work);

    value = gpio_get_value(btn->gpio);

    /*
     * 使用上拉電阻：
     * value == 0 代表按下
     * value == 1 代表放開
     */
    if (value == 0) {
        /*
         * 只有 released -> pressed 這一刻才送出按鍵事件。
         * 如果已經是 pressed，代表長按中，不重複送。
         */
        if (!btn->pressed) {
            btn->pressed = true;

            spin_lock_irqsave(&key_lock, flags);
            last_pressed_key = btn->key;
            spin_unlock_irqrestore(&key_lock, flags);

            pr_info("Button pressed: %c\n", btn->key);

            if (async_queue) {
                kill_fasync(&async_queue, SIGIO, POLL_IN);
            }
        }

        /*
         * 重點：
         * 只要按鈕還是低電位，就繼續排下一次檢查。
         * 這樣即使放開時 rising interrupt 沒有觸發，
         * delayed work 也會自己在下一次檢查時發現已經 release。
         */
        mod_delayed_work(system_wq,
                         &btn->work,
                         msecs_to_jiffies(DEBOUNCE_DELAY_MS));

    } else {
        /*
         * 放開只更新狀態，不送按鍵事件。
         */
        // if (btn->pressed) {
        //     btn->pressed = false;
        //     pr_info("Button released: %c\n", btn->key);
        // }
        if (btn->pressed) {
            btn->pressed = false;
            pr_info("Button released: %c\n", btn->key);

            // 💡 新增這段：把字元減去 32 (ASCII 轉大寫)，並發送 SIGIO
            spin_lock_irqsave(&key_lock, flags);
            last_pressed_key = btn->key - 32; // 'a' -> 'A', 'd' -> 'D'
            spin_unlock_irqrestore(&key_lock, flags);

            if (async_queue) {
                kill_fasync(&async_queue, SIGIO, POLL_IN);
            }
        }
    }
}
// static void btn_debounce_work(struct work_struct *work)
// {
//     struct btn_info *btn;
//     int value;
//     unsigned long flags;

//     btn = container_of(to_delayed_work(work), struct btn_info, work);

//     value = gpio_get_value(btn->gpio);

//     if (value == 0) {
//         /*
//          * 只有 released -> pressed 這一刻才送出按鍵事件。
//          * 如果已經是 pressed，代表長按中或彈跳，不重複送。
//          */
//         if (!btn->pressed) {
//             btn->pressed = true;

//             spin_lock_irqsave(&key_lock, flags);
//             last_pressed_key = btn->key;
//             spin_unlock_irqrestore(&key_lock, flags);

//             pr_info("Button pressed: %c\n", btn->key);

//             /*
//              * 通知 userspace 有按鍵事件
//              */
//             if (async_queue) {
//                 kill_fasync(&async_queue, SIGIO, POLL_IN);
//             }
//         }
//     } else {
//         /*
//          * 放開只更新狀態，不送按鍵事件。
//          * 這樣可以避免「長按放開時又觸發一次」。
//          */
//         if (btn->pressed) {
//             btn->pressed = false;
//             pr_info("Button released: %c\n", btn->key);
//         }
//     }
// }

/*************** 中斷服務常式 ISR **********************/
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

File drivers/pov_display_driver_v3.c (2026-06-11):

#include <linux/kernel.h>
#include <linux/init.h>
#include <linux/module.h>
#include <linux/spi/spi.h>
#include <linux/hrtimer.h>
#include <linux/ktime.h>
#include <linux/of.h>
#include <linux/atomic.h>
#include <linux/delay.h>
#include <linux/cdev.h>
#include <linux/device.h>
#include <linux/gpio.h>
#include <linux/interrupt.h>
#include <linux/math64.h>
#include <linux/spinlock.h>
#include <linux/ioctl.h>

#define NUM_LEDS 40
#define END_LEN 5
#define DEGREE_RESOLUTION 180                       // 一個圓切成360分
#define SPI_BUF_SIZE (4 + (NUM_LEDS * 4) + END_LEN) // Start(4) + LEDs(80) + End(4) = 88 Bytes
#define POV_IOC_MAGIC 'p'
#define POV_IOC_OFF   _IO(POV_IOC_MAGIC, 0)

// 驅動狀態與硬體指標
static struct spi_device *pov_spi_device;
static struct hrtimer pov_timer;
static ktime_t timer_interval;

// ============================================================
// Time-based angle estimation
// ============================================================

// 30 rps 時一圈約 33.333 ms
#define INITIAL_PERIOD_NS 33333333LL

// 依你的目標轉速設定合理範圍
// 20 rps = 50 ms, 40 rps = 25 ms
#define MIN_PERIOD_NS 20000000LL   // 20 ms
#define MAX_PERIOD_NS 100000000LL   // 100 ms

// 週期低通濾波：越大越穩，但反應越慢
// new_period = old * 0.8 + measured * 0.2
#define PERIOD_FILTER_OLD 8
#define PERIOD_FILTER_NEW 2

// 如果整張圖固定偏轉，可用這個微調 slice
#define ANGLE_OFFSET_SLICE 0

static ktime_t last_hall_time;
static s64 current_period_ns = INITIAL_PERIOD_NS;
static bool hall_synced = false;

// 用來防止上一筆 SPI 還沒傳完，Timer 又觸發下一筆的保護機制
static atomic_t spi_busy = ATOMIC_INIT(0);

// 將非同步傳輸需要的資料結構宣告為全域變數，並確保記憶體對齊以利 DMA 傳輸
static uint8_t frame_A[DEGREE_RESOLUTION][SPI_BUF_SIZE] ____cacheline_aligned;
static uint8_t frame_B[DEGREE_RESOLUTION][SPI_BUF_SIZE] ____cacheline_aligned;
static struct spi_transfer spi_xfer;
static struct spi_message spi_msg;

// character device
dev_t pov_dev_num = 0;
static struct class *pov_class;
static struct cdev pov_cdev;

// 宣告外部函式 (來自 magnet_driver.c)
extern void register_mag_callback(void (*callback_func)(ktime_t, s64));
extern void unregister_mag_callback(void);

// --- 雙緩衝指標與 Spinlock 保護機制 ---
static DEFINE_SPINLOCK(frame_lock);
static uint8_t (*active_frame)[SPI_BUF_SIZE] = frame_A;
static uint8_t (*back_frame)[SPI_BUF_SIZE] = frame_B;

static bool new_frame_ready = false; 
static bool is_writing = false;      // 記錄 User Space 是否正在執行 copy_from_user

// 控制邏輯變數
// static atomic_t current_slice = ATOMIC_INIT(0); // 馬達目前轉到第幾度，改為 atomic 讓 ISR 和 Timer 安全共用


static int get_current_slice_by_time(void)
{
    ktime_t now;
    s64 elapsed_ns;
    s64 period_ns;
    int slice;
    unsigned long flags;

    spin_lock_irqsave(&frame_lock, flags);
    period_ns = current_period_ns;
    now = ktime_get();
    elapsed_ns = ktime_to_ns(ktime_sub(now, last_hall_time));
    spin_unlock_irqrestore(&frame_lock, flags);

    if (period_ns <= 0) {
        return 0;
    }

    /*
     * elapsed_ns 正常情況下會小於 period_ns。
     * 如果因為剛啟動、漏 Hall 或 timer 延遲導致超過一圈，
     * 就用 Linux kernel 提供的 div64_s64 算商，再扣掉整圈數。
     */
    if (elapsed_ns >= period_ns) {
        s64 q = div64_s64(elapsed_ns, period_ns);
        elapsed_ns -= q * period_ns;
    }

    if (elapsed_ns < 0) {
        elapsed_ns = 0;
    }

    slice = div64_s64(elapsed_ns * DEGREE_RESOLUTION, period_ns);

    if (slice < 0) {
        slice = 0;
    }

    if (slice >= DEGREE_RESOLUTION) {
        slice = DEGREE_RESOLUTION - 1;
    }

    slice = (slice + ANGLE_OFFSET_SLICE) % DEGREE_RESOLUTION;

    return slice;
}
// --- 1. SPI 傳輸完成的回呼函式 ---
static void spi_complete_callback(void *context)
{
    atomic_set(&spi_busy, 0);
}

// --- 2. 更新畫面資料並發送 ---
// static void apa102_update_strip_async(void)
// {
//     int slice;

//     if (atomic_cmpxchg(&spi_busy, 0, 1))
//     {
//         return;
//     }

//     slice = atomic_read(&current_slice);

//     // 直接把 SPI 發送指標指向 active_frame 對應的 Slice
//     spin_lock(&frame_lock);
//     spi_xfer.tx_buf = active_frame[slice];
//     spin_unlock(&frame_lock);
//     spi_xfer.len = SPI_BUF_SIZE;

//     spi_message_init(&spi_msg);
//     spi_message_add_tail(&spi_xfer, &spi_msg);
//     spi_msg.complete = spi_complete_callback;

//     if (spi_async(pov_spi_device, &spi_msg) != 0)
//     {
//         atomic_set(&spi_busy, 0);
//     }

//     // 角度 +1。若馬達降速導致 Timer 跑超過 360，強制歸零避免記憶體越界
//     // 真正的精準 0 度歸零與 Swap 交由霍爾感測器 ISR 處理
//     slice++;
//     if (slice >= DEGREE_RESOLUTION) {
//         slice = 0; 
//     }
//     atomic_set(&current_slice, slice);
// }
static void apa102_update_strip_async(void)
{
    int slice;

    if (atomic_cmpxchg(&spi_busy, 0, 1))
    {
        return;
    }

    // 不再使用 current_slice++，改成根據 Hall 時間與目前時間估算角度
    slice = get_current_slice_by_time();

    // 直接把 SPI 發送指標指向 active_frame 對應的 Slice
    spin_lock(&frame_lock);
    spi_xfer.tx_buf = active_frame[slice];
    spin_unlock(&frame_lock);

    spi_xfer.len = SPI_BUF_SIZE;

    spi_message_init(&spi_msg);
    spi_message_add_tail(&spi_xfer, &spi_msg);
    spi_msg.complete = spi_complete_callback;

    if (spi_async(pov_spi_device, &spi_msg) != 0)
    {
        atomic_set(&spi_busy, 0);
    }
}


static void apa102_off(void)
{
    int i, j;

    while (atomic_cmpxchg(&spi_busy, 0, 1))
    {
        usleep_range(100, 200);
    }

    // 填寫全暗資料
    for (i = 0; i < NUM_LEDS; i++)
    {
        for (j = 0; j < DEGREE_RESOLUTION; j++)
        {
            frame_A[j][4 + i * 4 + 0] = 0xE0 | 0;
            frame_A[j][4 + i * 4 + 1] = 0x00;
            frame_A[j][4 + i * 4 + 2] = 0x00;
            frame_A[j][4 + i * 4 + 3] = 0x00;
            frame_B[j][4 + i * 4 + 0] = 0xE0 | 0;
            frame_B[j][4 + i * 4 + 1] = 0x00;
            frame_B[j][4 + i * 4 + 2] = 0x00;
            frame_B[j][4 + i * 4 + 3] = 0x00;
        }
    }

    spi_xfer.tx_buf = frame_A[0]; 
    spi_xfer.len = SPI_BUF_SIZE;
    spi_message_init(&spi_msg);
    spi_message_add_tail(&spi_xfer, &spi_msg);

    if (spi_sync(pov_spi_device, &spi_msg) == 0)
    {
        atomic_set(&spi_busy, 0);
    }
    else
    {
        atomic_set(&spi_busy, 0);
        pr_err("POV: Failed to send off signal\n");
    }
}
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

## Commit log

2026-04-17 my code
    [5V_Relay_HW-803.step, AEL-JR-101-1FRS.stp, Connector_5,5-2,1_DC00990-B.stp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]
2026-04-19 pov_display_driver_v3 & magnet_driver finish, app_pong building
2026-05-31 display driver nearly finish (both kernel & userspace)
2026-06-05 Can connect in by socket, but only test on localhost
2026-06-25 refine README.md & file structure
    [5V_Relay_HW-803.step, AEL-JR-101-1FRS.stp, Connector_5,5-2,1_DC00990-B.stp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]
